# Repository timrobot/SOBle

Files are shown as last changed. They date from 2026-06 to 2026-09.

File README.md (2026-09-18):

# SOBle - SO101 Platform over BLE

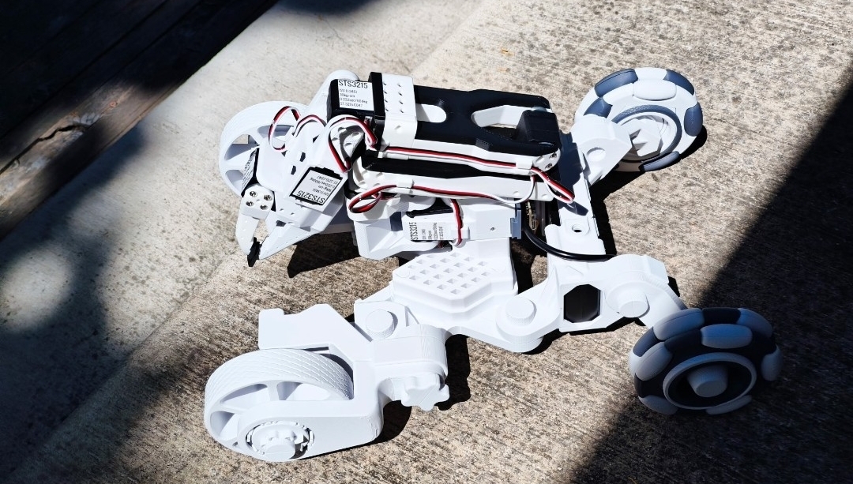
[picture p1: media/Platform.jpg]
SO101 Platform


*Image and Design attributed to @BIO-SS*

The SO101 Platform is a BLE-controlled four-wheeled differential drive with two powered wheels. It reports heading, pitch, roll, and wheel encoder positions. It is designed to work with the SO-101 robot arm, and supports an optional gripper-mounted camera for AprilTag detection or live video streaming over WiFi.

### Documentation 📖

For the full documention, check out the [wiki](https://github.com/timrobot/SOBle/wiki/Home) which contains both the [assembly guide](https://github.com/timrobot/SOBle/wiki/Assembly-Guide) and [tutorials](https://github.com/timrobot/SOBle/wiki/Home#Tutorials) for some classical algorithms involving Apriltags.

### Building the SO-101 Platform

You will need to first purchase the parts located in the [Sourcing Table](#sourcing-parts). Print out the parts in the [models folder](STL/), and then proceed to the [assembly guide](https://github.com/timrobot/SOBle/wiki/Assembly-Guide).

### Accessing the Viewer 📺

You can access the viewer [here](https://timrobot.github.io/SOBle). It allows you do to

 * ServoID flashing
 * Calibration file generation
 * Manual control over bluetooth
 * Sensor debugging

---

## Install

To control the robot over Python, you will need to install the SOBle package:

```bash
pip install "soble @ git+https://github.com/timrobot/SOBle.git@master"
```

---

## Quick usage

First, plug in the leader arm into your laptop. Make sure to record the port for your leader, as you will need it during connection.

```python
from soble import SO101Leader, SO101Platform

leader = SO101Leader("/dev/tty.usbmodem575E0032081")  # sub in the port of your leader here
leader.load_config("config.json")

platform = SO101Platform("Capybara")  # sub in the name of your robot/So101 Platform here

positions = leader.getMappedPositions()  # 6 ints, 0..4095
platform.setArmPositions(positions)
platform.drive(0, 0)

# if you have a raspi+camera attached, you can also detect apriltags
detections = platform.detectApriltags(estimate_tag_pose=True)
for tag_id, corners, R, t in detections:
    print(f"[{tag_id}]: {corners} {R} {t}")
```

---

## Sourcing parts

The following table lists the electronics you will need to purchase in addition to the prints you will need to make in [STL/](STL/), which will require 1-2 rolls of 1KG of PLA. Note that ideally you will need to solder at least a little, but solderless [hooked jumper wires](https://www.amazon.com/dp/B0BJ627S1X) are available for those who prefer not to.

| Part name | Qty | Unit Cost | Buy Link |
| --- | --- | --- | --- |
| Feetech STS3215 (1/345) | 2 | $12 | [Alibaba](https://www.alibaba.com/product-detail/Top-Seller-Low-Cost-Feetech-STS3215_1600999461525.html) |
| 7.4 V 2S LiPo battery (5200 mAh) | 1 | $36 | [Amazon](https://www.amazon.com/Zeee-Battery-5200mAh-Vehicles-Airplane/dp/B092CZGW2P) |
| Mini LiPo balance charger/discharger | 1 | $39 | [Amazon](https://www.amazon.com/B6-Battery-Charger-Discharger-Connectors/dp/B0F2H3XR6S) |
| Waveshare ESP32-S3-LCD-1.3 | 1 | $13 | [Waveshare](https://www.waveshare.com/esp32-s3-lcd-1.3.htm) (Standard version) |
| Barrel Connector (5.5x2.1) Male | 1 | $4 | [Amazon](https://www.amazon.com/Connector-Male-Female-Connectors-Security/dp/B0DVL9NDD1) |
| UBEC 5V 3A | 1 | $8 | [Amazon](https://www.amazon.com/jussming-Adjustable-UBEC-Regulator-Controllers/dp/B0GRGGM2T4) |
| USB-C female to 2-screw terminal | 1 | $8 | [Amazon](https://www.amazon.com/cablecc-Repair-Solderless-Connector-Terminal/dp/B0FY2HXYVF) |
| XT60 male to 2-screw terminal | 1 | $7 | [Amazon](https://www.amazon.com/YANBORONSN-Connectors-Terminal-Solderless-Aircraft/dp/B0FNJWYFT2) |
| Female to female jumper wires | 1 | $7 | [Amazon](https://www.amazon.com/EDGELEC-Breadboard-1pin-1pin-Connector-Multicolored/dp/B07GD312VG) |
| M2 x 6mm Socket Head Screws | 1 | $4 | [Amazon](https://www.amazon.com/Opfiue-100PCS-Socket-Screws-Stainless/dp/B0FVDZ7SZD) |
| USB-C to MicroUSB (2pcs) (optional) | 1 | $5 | [Amazon](https://www.amazon.com/JXMOX-Charger-Support-Compatible-Android/dp/B0D479B8DC) |
| Raspberry Pi Zero 2 W (optional) | 1 | $41 | [Amazon](https://www.amazon.com/CanaKit-Raspberry-Zero-Basic-Official/dp/B0CT1Y3CQJ) |
| Arducam Pi Camera Module 3 (IMX708, autofocus) (optional) | 1 | $34 | [Amazon](https://www.amazon.com/Arducam-Raspberry-Camera-Autofocus-15-22pin/dp/B0C9PYCV9S) |

Required electronics cost **$150**, primarily due to the battery and charger. Optional electronics add an additional **$80** (USB cable, Pi Zero 2 W, camera), for a grand total of **$230** plus filament.

The **SO101 follower arm** (Feetech servos and its own controller) is not included in the table above and must be purchased separately.

If you still need arm servos, order the two drive **STS3215** units from the table at the same time as the arm servos to save on shipping.

---

## Examples

A [3D viewer](https://github.com/timrobot/SOBle/releases) is available out of the box to control the robot with a leader arm. It also supports servo ID flashing, calibration, sensor displays, and 3D AprilTag detections—and uses the soble API directly, with no hidden functions. The code examples below demonstrate a few things you can do with the API.

| Script | Description |
| --- | --- |
| [`examples/lead-follow.py`](examples/lead-follow.py) | Send mapped leader positions → follower |
| [`examples/soble-app.py`](examples/soble-app.py) | Drive using WASD, mapped leader → follower, visualize tags on screen. *Raspi+Camera required.* |

---

## Code reference — Class `SO101Leader`

```python
from soble import SO101Leader

leader = SO101Leader("/dev/tty.usbmodem575E0032081") # Mac
leader = SO101Leader("/dev/ttyACM0") # Linux
leader = SO101Leader("COM3") # Windows
leader.load_config("config.json")  # or pass config= in the constructor

```

| Method | Returns | Notes |
| --- | --- | --- |
| `CalibrationConfig.from_path(path)` | `CalibrationConfig` | Load calibration from JSON (see [`examples/config.json`](examples/config.json)). |
| `CalibrationConfig.limits_arrays()` | `tuple[np.ndarray, np.ndarray]` | Leader and follower limit arrays, each shape **(6, 2)** with `[min, max]` per joint. |
| `SO101Leader(port, *, config=None, baud=1000000)` | — | **`port` required**. Serial starts on init. Pass `config` or call `load_config()` for mapping. |
| `load_config(config)` | `None` | Set leader/follower limit mapping from a `CalibrationConfig` or JSON path. |
| `config` (property) | `CalibrationConfig \| None` | Active calibration, if loaded. |
| `getArmPositions()` | `list[int]` | **6** leader joint raws **0 … 4095**, or **`[]`** if not ready. |
| `getMappedPositions()` | `list[int]` | **6** follower-mapped raws **0 … 4095**, or leader raws **1:1** if no config; **`[]`** if not ready. |
| `setArmPositions(joints)` | `None` | Engage leader torque, or pass **`[]`** to release (backdrivable; default). |

`load_config` accepts a `CalibrationConfig` instance or a path to the standard SO101 JSON file. See [`examples/config.json`](examples/config.json) and `CalibrationConfig` in `soble.calibration_config`.

## Code reference — Class `SO101Platform`

```python
from soble import SO101Platform

platform = SO101Platform("Capybara") # or whatever the name appears on the LCD

```

| Method | Returns | Notes |
| --- | --- | --- |
| `SO101Platform(device_name: str, *, reconnect_delay_s=0.25, log_state=True, autostart=True)` | — | With `autostart=True` (default), starts BLE on init; pass `autostart=False` to connect later via `start()`. |
| `start()` | `None` | *Optional.* Restart communication after `stop()`. |
| `stop()` | `None` | Stop communication; clear tag state. |
| `running` (property) | `bool` | `True` if alive, else `False` |
| `last_notify_age_s()` | `float` or `None` | Seconds since a data packet has arrived. |

### Core Commands

| Method | Returns | Notes |
| --- | --- | --- |
| `drive(left, right, left2=0, right2=0)` | — | Each **−125 … 125** (clamped). Optional `left2`/`right2` for the second wheel pair. |
| `wheelEncoders()` | `tuple[int, int, int, int]` | `(left, right, left2, right2)`, each **0 … 4095** (four 12-bit values packed in **6** bytes). |
| `setArmPositions(joints)` | — | **6** values, each **0 … 4095** (12-bit). Order **J1 … J6**. Pass **`[]`** to disengage arm. |
| `getArmPositions()` | `list[int]` | **6** raw encoder values **J1 … J6** from follower arm; **`[]`** if no state yet. |
| `setLegPositions(joints)` | — | **8** values, each **0 … 4095** (12-bit). Order **J11 … J18**. Pass **`[]`** to disengage legs. |
| `getLegPositions()` | `list[int]` | **8** raw encoder values **J11 … J18**; **`[]`** if no state yet. |
| `imuRotation()` | `tuple[float, float, float]` | IMU roll, pitch, heading in **degrees**. |
| `imuQuaternion()` | `tuple[float, float, float, float]` | IMU unit quaternion **(w, x, y, z)**. |

### Camera / AprilTag Commands

| Method | Returns | Notes |
| --- | --- | --- |
| `raspiAlive()` | `bool` | Pi serial seen recently. |
| `detectApriltags(estimate_tag_pose=False, camera_params=..., tag_size=3)` | `list` | Tag id plus four corner `(x, y)` pairs (**lb, rb, rt, lt**). Returns **`[]`** if no state yet or no tags in view. Pass `estimate_tag_pose=True` for `(tag_id, corners, R, tvec)` per tag. `tag_size` is the physical outer edge length in your chosen unit (e.g. inches); `tvec` uses the same unit. |
| `setTagFamily(family)` | — | `'tag16h5'`, `'tag25h9'`, or `'tag36h11'`. |

#### AprilTags — corners and image

*Specifications:*

| Item | Value |
| --- | --- |
| Image size | **1280 × 720** pixels |
| Tag family | **tag16h5** by default; use `setTagFamily()` for **tag25h9** or **tag36h11** |
| Corner order | **lb, rb, rt, lt** — each corner `(x, y)` float pixels |
| `x` range | **0 … 1280** |
| `y` range | **0 … 720** |
| Max tags | **10** |
| `R` | **3 × 3** rotation matrix (`np.ndarray`, `float64`) |
| `t` | **3 × 1** translation vector (`np.ndarray`, `float64`); same unit as `tag_size` when pose is estimated |

**Example** — two tag16h5 tags in view:

```python
>>> platform.detectApriltags()
[
    (0, [
        (612.4, 388.2),   # lb
        (667.8, 388.2),   # rb
        (667.8, 331.6),   # rt
        (612.4, 331.6),   # lt
    ]),
    (3, [
        (118.4, 142.3),
        (182.0, 140.0),
        (180.2, 198.1),
        (120.0, 200.5),
    ]),
]
```

Each list entry is `(tag_id, corners_px)` with **four** `(x, y)` pixel pairs in **lb → rb → rt → lt** order.

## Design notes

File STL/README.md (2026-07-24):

## Required STL Print List (VEX front wheel)

> Note: This list assumes that you are using the VEX 4" Traction wheel for the front wheel. If you aren't please refer to the list at the bottom of the page. You will be required to print the wheel in TPU for the wheel to have proper grip.

| STL part | Qty | Repo link |
| ---- | --- | ---- |
| Supported Ball Bearing | 24 | [Supported Ball Bearing.stl](KiloChassis/Bearing/Supported%20Ball%20Bearing.stl) |
| Omni Wheel Core | 2 | [Omni Wheel Core.stl](KiloChassis/Rear%20Deadwheel/Omni%20Wheel/Omni%20Wheel%20Core.stl) |
| Bearing Inner Ring | 4 | [Bearing Inner Ring.stl](KiloChassis/Bearing/Bearing%20Inner%20Ring.stl) |
| Ball Retainer | 4 | [Ball Retainer.stl](KiloChassis/Bearing/Ball%20Retainer.stl) |
| Roller | 20 | [Roller.stl](KiloChassis/Rear%20Deadwheel/Omni%20Wheel/Roller.stl) |
| Omni Wheel Frame | 8 | [Omni Wheel Frame.stl](KiloChassis/Rear%20Deadwheel/Omni%20Wheel/Omni%20Wheel%20Frame.stl) |
| Hub Retaining Ring | 4 | [Hub Retaining Ring.stl](KiloChassis/Rear%20Deadwheel/Omni%20Wheel/Hub%20Retaining%20Ring.stl) |
| Rear Base | 1 | [Rear Base.stl](KiloChassis/Base%20Components/Rear%20Base.stl) |
| Main Base Bolt | 4 | [Main Base Bolt v2.stl](KiloChassis/Bolts/Main%20Base%20Bolt%20v2.stl) |
| Rear Drive Bolt | 2 | [Rear Drive Bolt.stl](KiloChassis/Bolts/Rear%20Drive%20Bolt.stl) |
| Rear Deadwheel Bracket | 2 | [Rear Deadwheel Bracket.stl](KiloChassis/Rear%20Deadwheel/Rear%20Deadwheel%20Bracket.stl) |
| Rear Wheel Nut | 2 | [Rear Wheel Nut.stl](KiloChassis/Rear%20Deadwheel/Rear%20Wheel%20Nut.stl) |
| Servo Coupler | 2 | [Servo Coupler.stl](KiloChassis/Front%20Drive/VEX%20Front%20Axle/Servo%20Coupler.stl) |
| Servo Clamp | 2 | [Servo Clamp.stl](KiloChassis/Front%20Drive/Servo%20Clamp.stl) |
| Servo Bracket Left | 1 | [Servo Bracket Left.stl](KiloChassis/Front%20Drive/Servo%20Bracket%20Left.stl) |
| Servo Bracket Right | 1 | [Servo Bracket Right.stl](KiloChassis/Front%20Drive/Servo%20Bracket%20Right.stl) |
| Arm Base | 1 | [Arm Base.stl](KiloChassis/Base%20Components/Arm%20Base.stl) |
| Wheel Bearing Bracket Left | 1 | [Wheel Bearing Bracket Left.stl](KiloChassis/Front%20Drive/Wheel%20Bearing%20Bracket%20Left.stl) |
| Wheel Bearing Bracket Right | 1 | [Wheel Bearing Bracket Right.stl](KiloChassis/Front%20Drive/Wheel%20Bearing%20Bracket%20Right.stl) |
| Front Axle Halve | 4 | [Front Axle Halve.stl](KiloChassis/Front%20Drive/VEX%20Front%20Axle/Front%20Axle%20Halve.stl) |
| Front Drive Bolt | 2 | [Front Drive Bolt v2.stl](KiloChassis/Bolts/Front%20Drive%20Bolt%20v2.stl) |
| Arm Retainer Pin Halve | 8 | [Arm Retainer Pin Halve.stl](KiloChassis/Base%20Components/Arm%20Retainer/Arm%20Retainer%20Pin%20Halve.stl) |
| Arm Pin Half Bracket | 4 | [Arm Pin Half Bracket.stl](KiloChassis/Base%20Components/Arm%20Retainer/Arm%20Pin%20Half%20Bracket.stl) |
| Arm Pin Mini Bracket | 4 | [Arm Pin Mini Bracket.stl](KiloChassis/Base%20Components/Arm%20Retainer/Arm%20Pin%20Mini%20Bracket.stl) |
| Arm Pin Bolt | 4 | [Arm Pin Bolt.stl](KiloChassis/Bolts/Arm%20Pin%20Bolt.stl) |
| ESP32 Mount | 1 | [ESP32 Mount.stl](KiloChassis/Base%20Components/ESP32%20Mount.stl) |
| ESP32 Bolt | 1 | [ESP32 Bolt.stl](KiloChassis/Bolts/ESP32%20Bolt.stl) |
| Bus Adapter Bracket | 1 | [Bus Adapter Bracket.stl](KiloChassis/Bus%20Adapter/Bus%20Adapter%20Bracket.stl) |
| Bus Adapter Clamping Foot | 2 | [Bus Adapter Clamping Foot.stl](KiloChassis/Bus%20Adapter/Bus%20Adapter%20Clamping%20Foot.stl) |
| Bus Adapter Clamp Bolt | 2 | [Bus Adapter Clamp Bolt.stl](KiloChassis/Bolts/Bus%20Adapter%20Clamp%20Bolt.stl) |
| Bus Adapter Bracket Top | 1 | [Bus Adapter Bracket Top.stl](KiloChassis/Bus%20Adapter/Bus%20Adapter%20Bracket%20Top.stl) |
| Bus Adapter Bracket Bottom | 1 | [Bus Adapter Bracket Bottom.stl](KiloChassis/Bus%20Adapter/Bus%20Adapter%20Bracket%20Bottom.stl) |
| Bus Adapter Bracket Retainer | 1 | [Bus Adapter Bracket Retainer.stl](KiloChassis/Bus%20Adapter/Bus%20Adapter%20Bracket%20Retainer.stl) |
| Bus Adapter Retainer Bolt | 1 | [Bus Adapter Retainer Bolt.stl](KiloChassis/Bolts/Bus%20Adapter%20Retainer%20Bolt.stl) |
| Battery Lock | 1 | [Battery Lock.stl](KiloChassis/Base%20Components/Battery%20Lock.stl) |

## Required STL Print List (TPU front wheel)

| STL part | Qty | Repo link |
| ---- | --- | ---- |
| Supported Ball Bearing | 24 | [Supported Ball Bearing.stl](KiloChassis/Bearing/Supported%20Ball%20Bearing.stl) |
| Omni Wheel Core | 2 | [Omni Wheel Core.stl](KiloChassis/Rear%20Deadwheel/Omni%20Wheel/Omni%20Wheel%20Core.stl) |
| Bearing Inner Ring | 4 | [Bearing Inner Ring.stl](KiloChassis/Bearing/Bearing%20Inner%20Ring.stl) |
| Ball Retainer | 4 | [Ball Retainer.stl](KiloChassis/Bearing/Ball%20Retainer.stl) |
| Roller | 20 | [Roller.stl](KiloChassis/Rear%20Deadwheel/Omni%20Wheel/Roller.stl) |
| Omni Wheel Frame | 8 | [Omni Wheel Frame.stl](KiloChassis/Rear%20Deadwheel/Omni%20Wheel/Omni%20Wheel%20Frame.stl) |
| Hub Retaining Ring | 4 | [Hub Retaining Ring.stl](KiloChassis/Rear%20Deadwheel/Omni%20Wheel/Hub%20Retaining%20Ring.stl) |
| Rear Base | 1 | [Rear Base.stl](KiloChassis/Base%20Components/Rear%20Base.stl) |
| Main Base Bolt | 4 | [Main Base Bolt v2.stl](KiloChassis/Bolts/Main%20Base%20Bolt%20v2.stl) |
| Rear Drive Bolt | 2 | [Rear Drive Bolt.stl](KiloChassis/Bolts/Rear%20Drive%20Bolt.stl) |
| Rear Deadwheel Bracket | 2 | [Rear Deadwheel Bracket.stl](KiloChassis/Rear%20Deadwheel/Rear%20Deadwheel%20Bracket.stl) |
| Rear Wheel Nut | 2 | [Rear Wheel Nut.stl](KiloChassis/Rear%20Deadwheel/Rear%20Wheel%20Nut.stl) |
| Servo Coupler | 2 | [Servo Coupler.stl](KiloChassis/Front%20Drive/Front%20Axle/Servo%20Coupler.stl) |
| Servo Clamp | 2 | [Servo Clamp.stl](KiloChassis/Front%20Drive/Servo%20Clamp.stl) |
| Servo Bracket Left | 1 | [Servo Bracket Left.stl](KiloChassis/Front%20Drive/Servo%20Bracket%20Left.stl) |
| Servo Bracket Right | 1 | [Servo Bracket Right.stl](KiloChassis/Front%20Drive/Servo%20Bracket%20Right.stl) |
| Arm Base | 1 | [Arm Base.stl](KiloChassis/Base%20Components/Arm%20Base.stl) |
| Wheel Bearing Bracket Left | 1 | [Wheel Bearing Bracket Left.stl](KiloChassis/Front%20Drive/Wheel%20Bearing%20Bracket%20Left.stl) |
| Wheel Bearing Bracket Right | 1 | [Wheel Bearing Bracket Right.stl](KiloChassis/Front%20Drive/Wheel%20Bearing%20Bracket%20Right.stl) |
| Front Axle Halve | 4 | [Front Axle Halve.stl](KiloChassis/Front%20Drive/Front%20Axle/Front%20Axle%20Halve.stl) |
| Front Axle Halve | 4 | [Front Axle Halve.stl](KiloChassis/Front%20Drive/Front%20Axle/Front%20Axle%20Halve.stl) |
| Front Axle Clip | 2 | [Front Axle Clip.stl](KiloChassis/Front%20Drive/Front%20Axle/Front%20Axle%20Clip.stl) |
| Front Wheels Grippy v2 | 2 | [Front Wheels Grippy v2.stl](KiloChassis/Front%20Drive/Front%20Wheels%20Grippy%20v2.stl) |
| Front Drive Bolt | 2 | [Front Drive Bolt v2.stl](KiloChassis/Bolts/Front%20Drive%20Bolt%20v2.stl) |
| Arm Retainer Pin Halve | 8 | [Arm Retainer Pin Halve.stl](KiloChassis/Base%20Components/Arm%20Retainer/Arm%20Retainer%20Pin%20Halve.stl) |
| Arm Pin Half Bracket | 4 | [Arm Pin Half Bracket.stl](KiloChassis/Base%20Components/Arm%20Retainer/Arm%20Pin%20Half%20Bracket.stl) |
| Arm Pin Mini Bracket | 4 | [Arm Pin Mini Bracket.stl](KiloChassis/Base%20Components/Arm%20Retainer/Arm%20Pin%20Mini%20Bracket.stl) |
| Arm Pin Bolt | 4 | [Arm Pin Bolt.stl](KiloChassis/Bolts/Arm%20Pin%20Bolt.stl) |
| ESP32 Mount | 1 | [ESP32 Mount.stl](KiloChassis/Base%20Components/ESP32%20Mount.stl) |
| ESP32 Bolt | 1 | [ESP32 Bolt.stl](KiloChassis/Bolts/ESP32%20Bolt.stl) |
| Bus Adapter Bracket | 1 | [Bus Adapter Bracket.stl](KiloChassis/Bus%20Adapter/Bus%20Adapter%20Bracket.stl) |
| Bus Adapter Clamping Foot | 2 | [Bus Adapter Clamping Foot.stl](KiloChassis/Bus%20Adapter/Bus%20Adapter%20Clamping%20Foot.stl) |
| Bus Adapter Clamp Bolt | 2 | [Bus Adapter Clamp Bolt.stl](KiloChassis/Bolts/Bus%20Adapter%20Clamp%20Bolt.stl) |
| Bus Adapter Bracket Top | 1 | [Bus Adapter Bracket Top.stl](KiloChassis/Bus%20Adapter/Bus%20Adapter%20Bracket%20Top.stl) |
| Bus Adapter Bracket Bottom | 1 | [Bus Adapter Bracket Bottom.stl](KiloChassis/Bus%20Adapter/Bus%20Adapter%20Bracket%20Bottom.stl) |
| Bus Adapter Bracket Retainer | 1 | [Bus Adapter Bracket Retainer.stl](KiloChassis/Bus%20Adapter/Bus%20Adapter%20Bracket%20Retainer.stl) |
| Bus Adapter Retainer Bolt | 1 | [Bus Adapter Retainer Bolt.stl](KiloChassis/Bolts/Bus%20Adapter%20Retainer%20Bolt.stl) |
| Battery Lock | 1 | [Battery Lock.stl](KiloChassis/Base%20Components/Battery%20Lock.stl) |

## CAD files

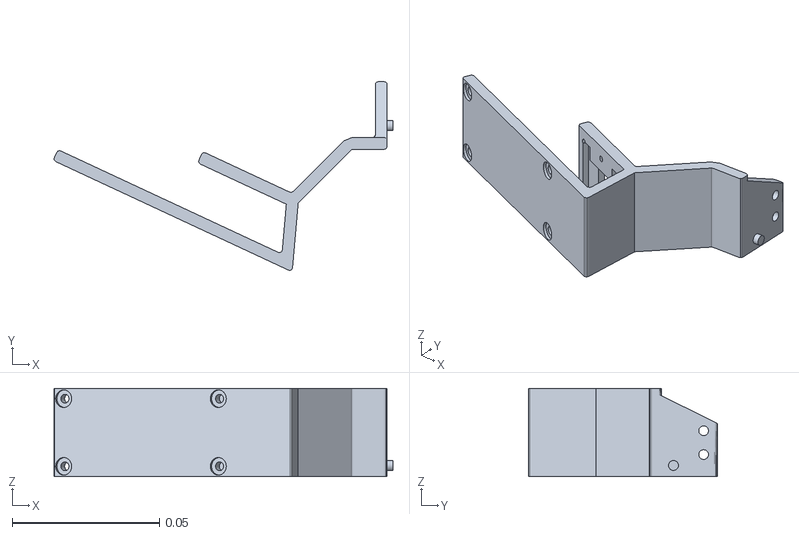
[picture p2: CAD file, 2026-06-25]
Simulation/SO101/assets/SO-ARM101_IMX708_wrist_mount.stl
0.115 x 0.0641 x 0.03

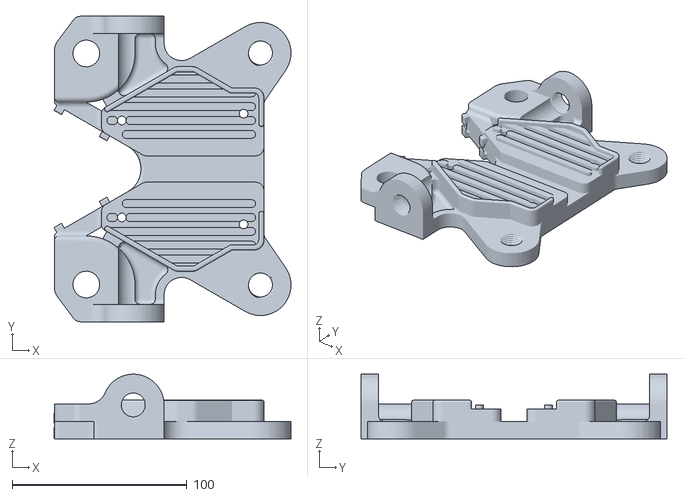
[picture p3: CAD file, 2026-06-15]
STL/KiloChassis/Base Components/Arm Base.stl
135.8 x 175.1 x 37.0

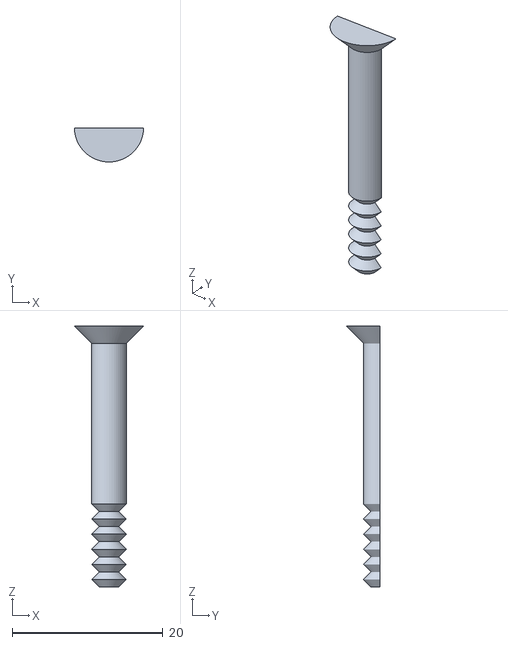
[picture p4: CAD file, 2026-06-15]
STL/KiloChassis/Base Components/Arm Retainer/Arm Retainer Pin Halve.stl
9.20 x 4.50 x 34.6

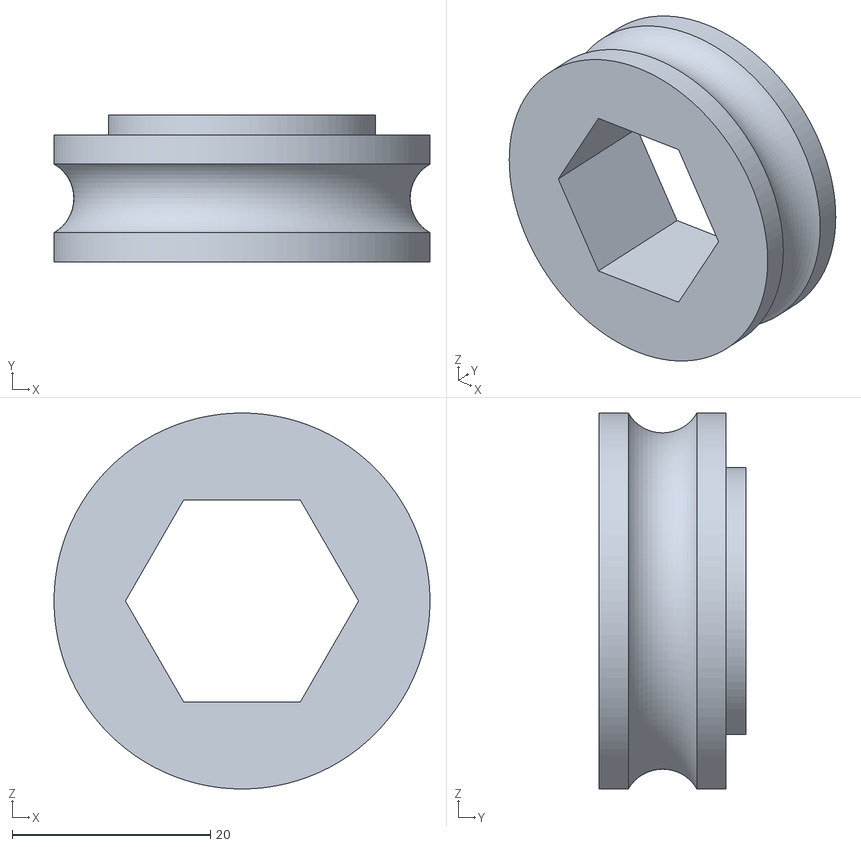
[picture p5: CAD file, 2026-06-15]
STL/KiloChassis/Bearing/Bearing Inner Ring.stl
38.0 x 14.8 x 38.0

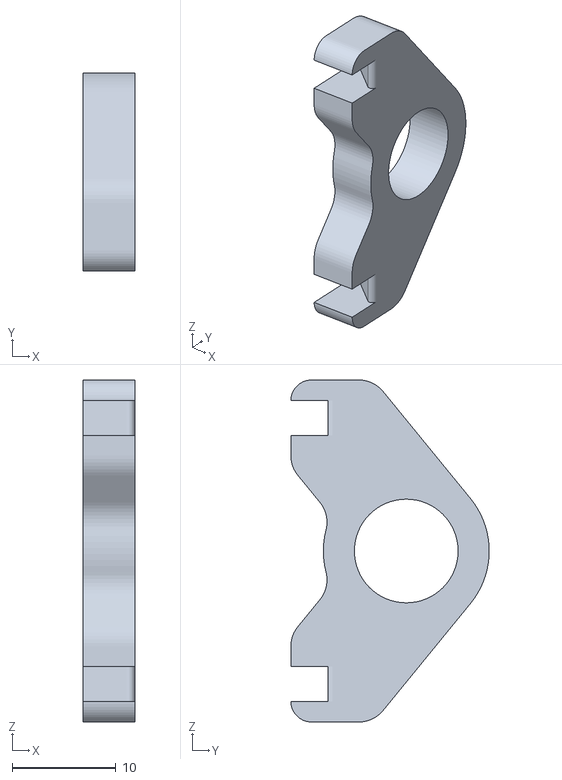
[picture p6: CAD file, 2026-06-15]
STL/KiloChassis/Bus Adapter/Bus Adapter Bracket Retainer.stl
5.00 x 19.1 x 33.0

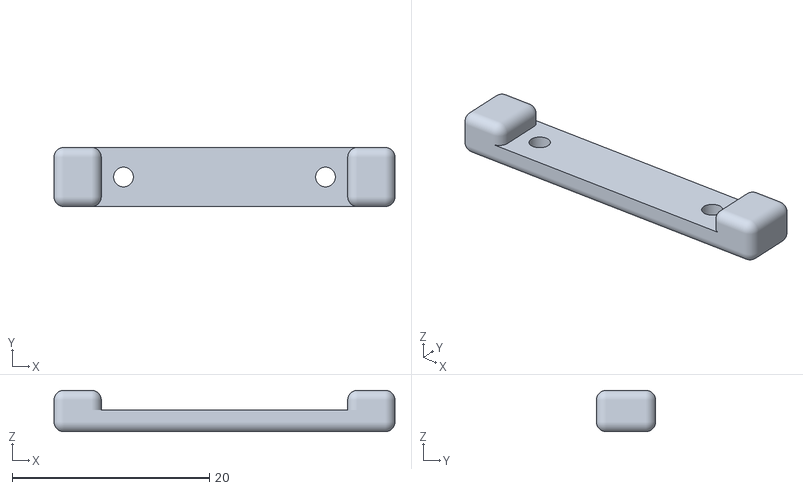
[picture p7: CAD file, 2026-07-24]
STL/KiloChassis/Front Drive/Servo Clamp.stl
34.6 x 6.00 x 4.20

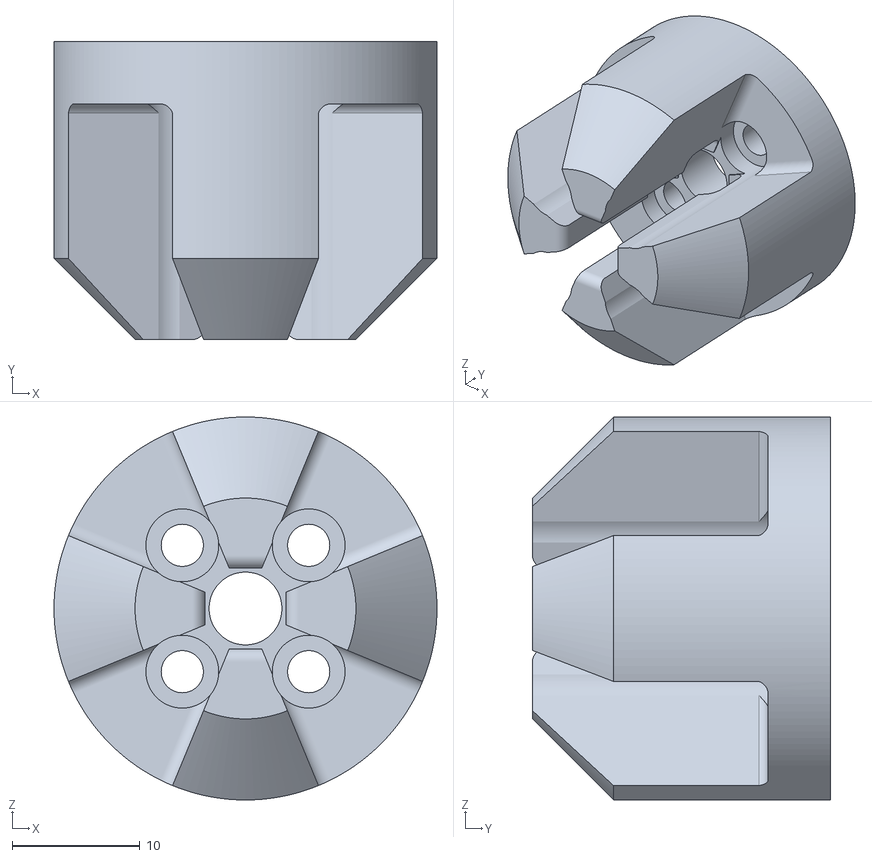
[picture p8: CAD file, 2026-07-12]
STL/KiloChassis/Front Drive/VEX Front Axle/Servo Coupler.stl
30.0 x 23.3 x 30.0

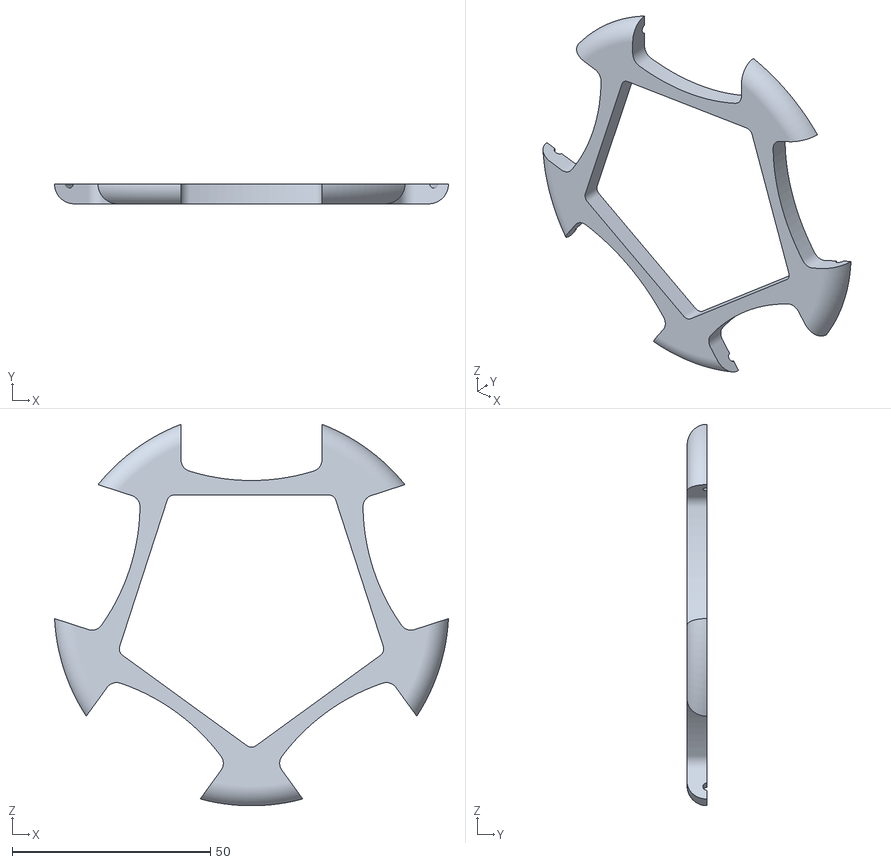
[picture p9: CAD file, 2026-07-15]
STL/KiloChassis/Rear Deadwheel/Omni Wheel/Omni Wheel Frame.stl
99.5 x 5.00 x 96.3

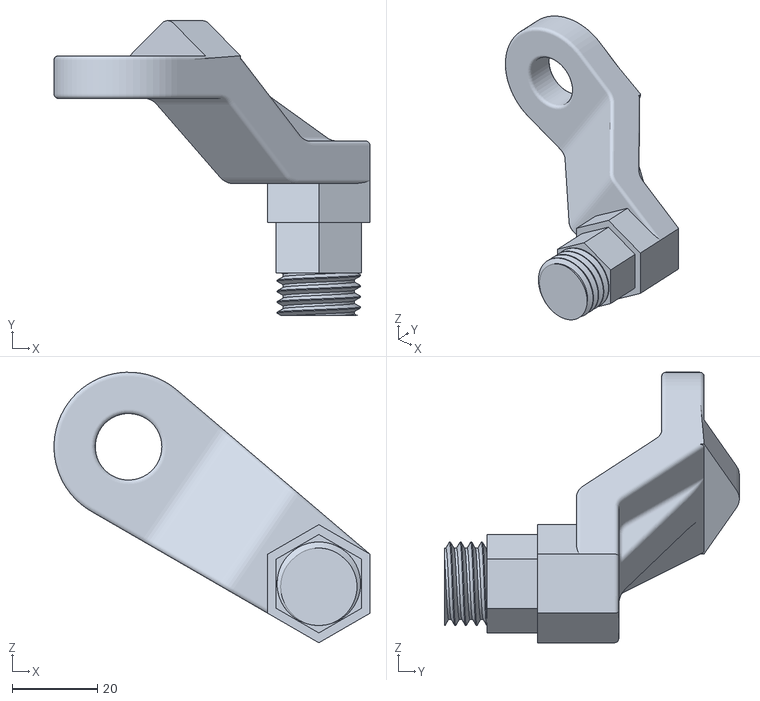
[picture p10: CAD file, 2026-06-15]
STL/KiloChassis/Rear Deadwheel/Rear Deadwheel Bracket.stl
74.1 x 69.2 x 63.5

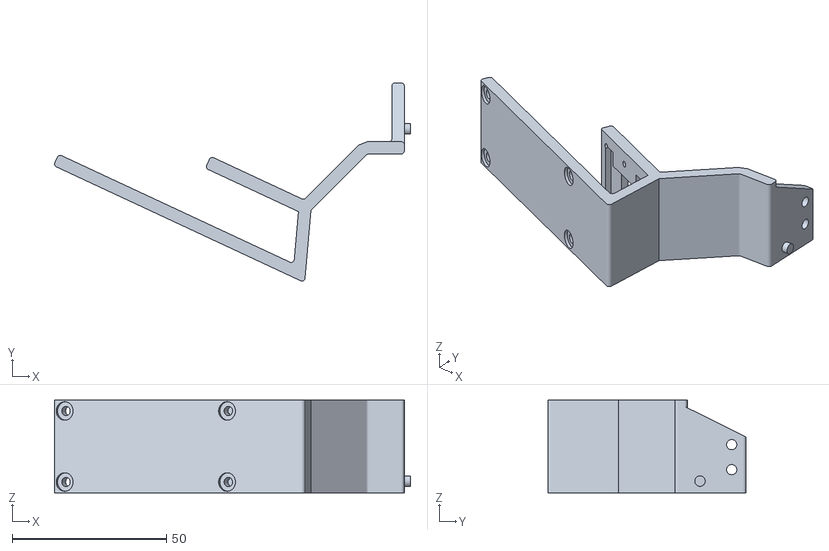
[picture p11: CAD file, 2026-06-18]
STL/Optional/SO-ARM101_IMX708_wrist_mount.stl
115.2 x 64.1 x 30.0

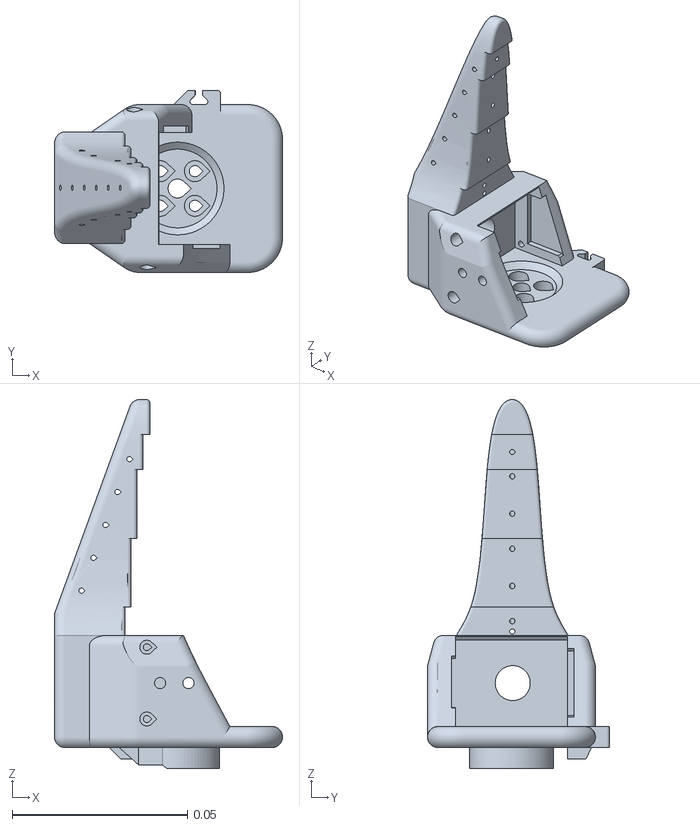
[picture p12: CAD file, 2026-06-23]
Simulation/SO101/assets/wrist_roll_follower_so101_v1.stl
0.0652 x 0.052 x 0.105

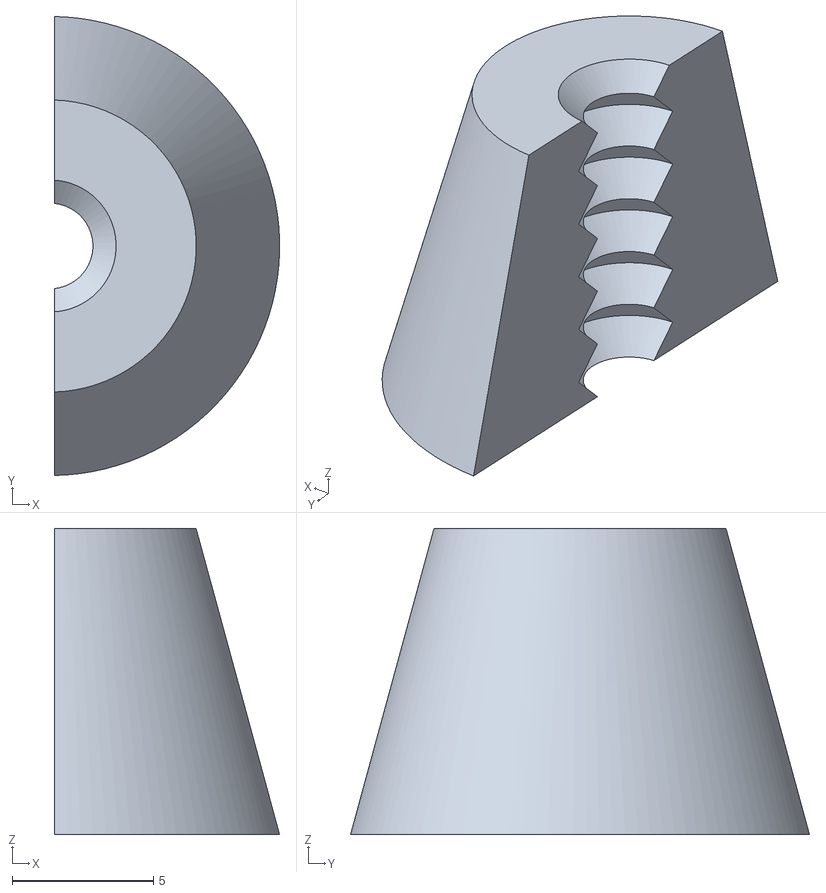
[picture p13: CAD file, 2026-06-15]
STL/KiloChassis/Base Components/Arm Retainer/Arm Pin Half Bracket.stl
7.96 x 16.2 x 10.8

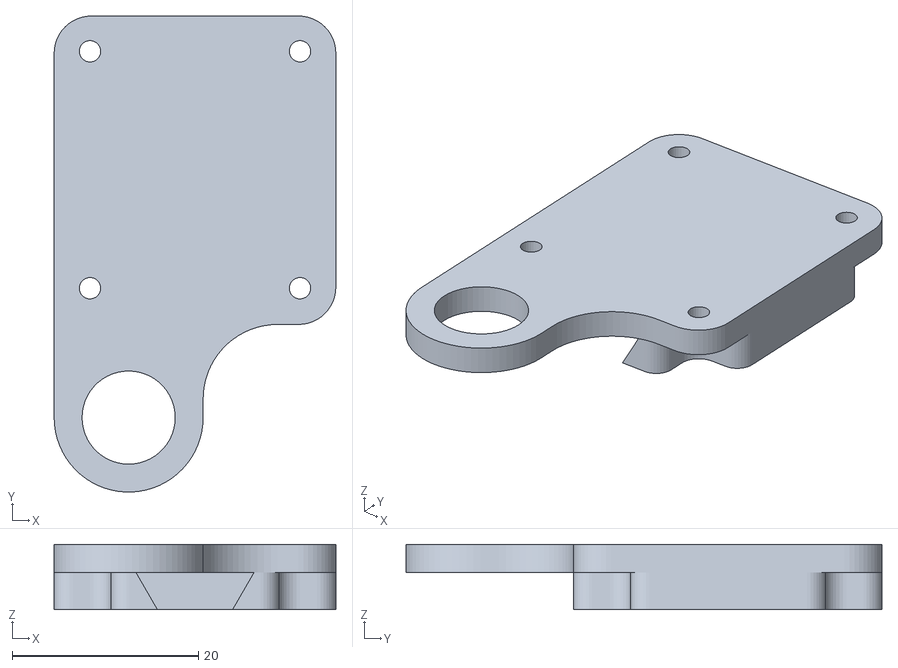
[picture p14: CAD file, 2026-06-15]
STL/KiloChassis/Base Components/ESP32 Mount.stl
30.2 x 51.1 x 7.00

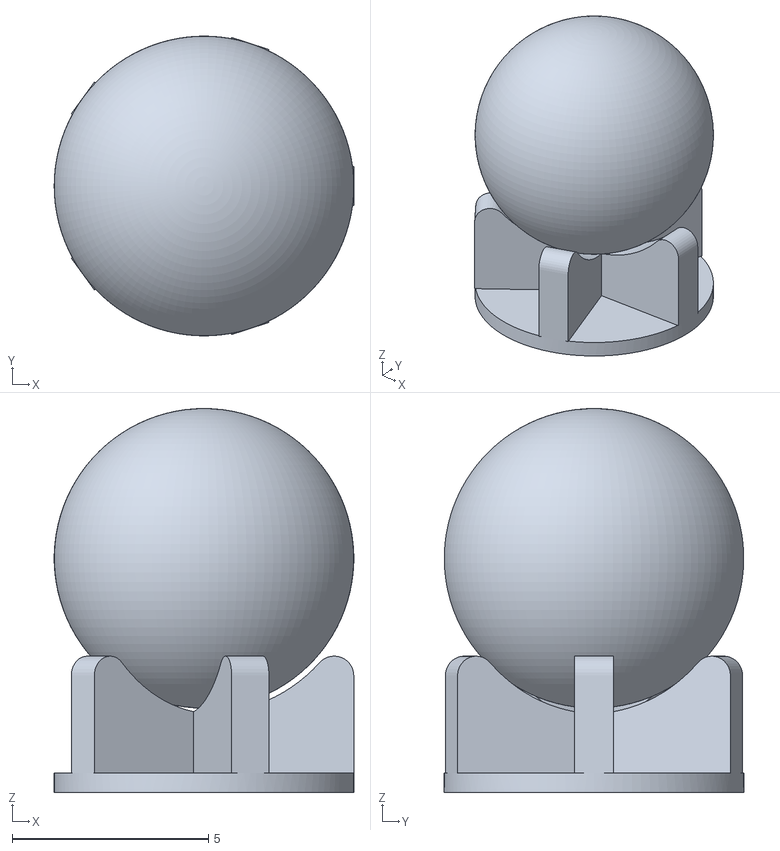
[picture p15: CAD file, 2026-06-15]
STL/KiloChassis/Bearing/Supported Ball Bearing.stl
7.64 x 7.64 x 9.79

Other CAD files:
STL/KiloChassis/Bus Adapter/Bus Adapter Bracket.stl
STL/KiloChassis/Front Drive/Front Wheels Grippy v2.stl
STL/KiloChassis/Front Drive/VEX Front Axle/Front Axle Halve.stl
STL/KiloChassis/Rear Deadwheel/Omni Wheel/Roller.stl
STL/KiloChassis/Base Components/Arm Retainer/Arm Pin Mini Bracket.stl
STL/KiloChassis/Base Components/Battery Lock.stl
STL/KiloChassis/Base Components/Rear Base.stl
STL/KiloChassis/Bearing/Ball Retainer.stl
STL/KiloChassis/Bolts/Arm Pin Bolt.stl
STL/KiloChassis/Bolts/Bus Adapter Clamp Bolt.stl
STL/KiloChassis/Bolts/Bus Adapter Retainer Bolt.stl
STL/KiloChassis/Bolts/ESP32 Bolt.stl
STL/KiloChassis/Bolts/Front Drive Bolt v2.stl
STL/KiloChassis/Bolts/Front Drive Bolt.stl
STL/KiloChassis/Bolts/Main Base Bolt v2.stl
STL/KiloChassis/Bolts/Main Base Bolt.stl
STL/KiloChassis/Bolts/Rear Drive Bolt.stl
STL/KiloChassis/Bus Adapter/Bus Adapter Bracket Bottom.stl
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

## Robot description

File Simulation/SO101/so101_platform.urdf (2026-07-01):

<?xml version="1.0"?>
<!-- SO-101 differential-drive mobile base (STS3215 1/345 front wheels).
     Converted from so101_platform.xml (MuJoCo).
     Axes: +X forward, +Y left, +Z up (matches so101_new_calib / Panda sim).
     Wheel layout:
      distance from center to front wheels (+X): 5.75 in
      distance from wheel to wheel: 9.5 in
      distance from center to back wheels (-X): 5.75 in
      wheel diameter: 4 in
      wheel width: 1 in
     Front left/right wheels: continuous joints (encoder angle maps to 12-bit raw).
     Rear wheels: passive omni casters (MuJoCo ball joints; URDF uses continuous spin). -->
<robot name="so101_platform">

  <!-- Ground / odometry frame. Platform body origin sits at wheel-axle height. -->
  <link name="base_footprint"/>

  <link name="platform">
    <inertial>
      <origin xyz="0 0 0" rpy="0 0 0"/>
      <mass value="2.5"/>
      <inertia ixx="0.02" iyy="0.03" izz="0.04" ixy="0" ixz="0" iyz="0"/>
    </inertial>
    <visual name="chassis_visual">
      <origin xyz="0 0 0" rpy="0 0 3.141592653589793"/>
      <geometry>
        <mesh filename="assets/ChassisV2.stl"/>
      </geometry>
      <material name="chassis_gray">
        <color rgba="0.15 0.15 0.15 1"/>
      </material>
    </visual>
    <collision name="chassis_collision">
      <origin xyz="0 0 0" rpy="0 0 0"/>
      <geometry>
        <box size="0.3048 0.254 0.0508"/>
      </geometry>
    </collision>
  </link>

  <!-- MuJoCo freejoint → URDF floating base (6-DOF). -->
  <joint name="platform_free" type="floating">
    <parent link="base_footprint"/>
    <child link="platform"/>
    <origin xyz="0 0 0.0508" rpy="0 0 0"/>
  </joint>

  <!-- Mount frame for SO101 arm (matches arm_mount site in MJCF). -->
  <link name="arm_mount"/>

  <joint name="arm_mount_joint" type="fixed">
    <parent link="platform"/>
    <child link="arm_mount"/>
    <origin xyz="0 0 0" rpy="0 0 0"/>
  </joint>

  <link name="wheel_fl">
    <inertial>
      <origin xyz="0 0 0" rpy="0 0 0"/>
      <mass value="0.15"/>
      <inertia ixx="0.0002" iyy="0.0003" izz="0.0002" ixy="0" ixz="0" iyz="0"/>
    </inertial>
    <visual name="wheel_fl_visual">
      <origin xyz="0 0 0" rpy="0 0 0"/>
      <geometry>
        <mesh filename="assets/FrontWheel.stl"/>
      </geometry>
      <material name="wheel_dark">
        <color rgba="0.1 0.1 0.1 1"/>
      </material>
    </visual>
    <collision name="wheel_fl_collision">
      <origin xyz="0 0 0" rpy="1.5707963267948966 0 0"/>
      <geometry>
        <cylinder radius="0.0508" length="0.0254"/>
      </geometry>
    </collision>
  </link>

  <!-- STS servo ID 7 on hardware. -->
  <joint name="wheel_left" type="continuous">
    <parent link="platform"/>
    <child link="wheel_fl"/>
    <origin xyz="0.14605 0.12065 0" rpy="0 0 0"/>
    <axis xyz="0 1 0"/>
    <dynamics damping="0.60" friction="0.052"/>
  </joint>

  <link name="wheel_fr">
    <inertial>
      <origin xyz="0 0 0" rpy="0 0 0"/>
      <mass value="0.15"/>
      <inertia ixx="0.0002" iyy="0.0003" izz="0.0002" ixy="0" ixz="0" iyz="0"/>
    </inertial>
    <visual name="wheel_fr_visual">
      <origin xyz="0 0 0" rpy="0 0 0"/>
      <geometry>
        <mesh filename="assets/FrontWheel.stl"/>
      </geometry>
      <material name="wheel_dark"/>
    </visual>
    <collision name="wheel_fr_collision">
      <origin xyz="0 0 0" rpy="1.5707963267948966 0 0"/>
      <geometry>
        <cylinder radius="0.0508" length="0.0254"/>
      </geometry>
    </collision>
  </link>

  <!-- STS servo ID 8 on hardware. -->
  <joint name="wheel_right" type="continuous">
    <parent link="platform"/>
    <child link="wheel_fr"/>
    <origin xyz="0.14605 -0.12065 0" rpy="0 0 0"/>
    <axis xyz="0 1 0"/>
    <dynamics damping="0.60" friction="0.052"/>
  </joint>

  <link name="wheel_rl">
    <inertial>
      <origin xyz="0 0 0" rpy="0 0 0"/>
      <mass value="0.10"/>
      <inertia ixx="0.00015" iyy="0.0002" izz="0.00015" ixy="0" ixz="0" iyz="0"/>
    </inertial>
    <visual name="wheel_rl_visual">
      <origin xyz="0 0 0" rpy="0 0 0"/>
      <geometry>
        <mesh filename="assets/Omniwheel.stl"/>
      </geometry>
      <material name="omni_gray">
        <color rgba="0.35 0.35 0.35 1"/>
      </material>
    </visual>
    <collision name="wheel_rl_collision">
      <origin xyz="0 0 0" rpy="1.5707963267948966 0 0"/>
      <geometry>
        <cylinder radius="0.0508" length="0.0254"/>
      </geometry>
    </collision>
  </link>

  <!-- Passive omni caster (MJCF ball joint; URDF models wheel spin only). -->
  <joint name="omni_left" type="continuous">
    <parent link="platform"/>
    <child link="wheel_rl"/>
    <origin xyz="-0.14605 0.12065 0" rpy="0 0 0"/>
    <axis xyz="0 1 0"/>
    <dynamics damping="0.01" friction="0.001"/>
  </joint>

  <link name="wheel_rr">
    <inertial>
      <origin xyz="0 0 0" rpy="0 0 0"/>
      <mass value="0.10"/>
      <inertia ixx="0.00015" iyy="0.0002" izz="0.00015" ixy="0" ixz="0" iyz="0"/>
    </inertial>
    <visual name="wheel_rr_visual">
      <origin xyz="0 0 0" rpy="0 0 0"/>
      <geometry>
        <mesh filename="assets/Omniwheel.stl"/>
      </geometry>
      <material name="omni_gray"/>
    </visual>
    <collision name="wheel_rr_collision">
      <origin xyz="0 0 0" rpy="1.5707963267948966 0 0"/>
      <geometry>
        <cylinder radius="0.0508" length="0.0254"/>
      </geometry>
    </collision>
  </link>

  <joint name="omni_right" type="continuous">
    <parent link="platform"/>
    <child link="wheel_rr"/>
    <origin xyz="-0.14605 -0.12065 0" rpy="0 0 0"/>
    <axis xyz="0 1 0"/>
    <dynamics damping="0.01" friction="0.001"/>
  </joint>

</robot>

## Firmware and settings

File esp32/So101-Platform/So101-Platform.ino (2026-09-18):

// BLE robot control (So101-Platform protocol), STS bus, QMI8658 IMU, ST7789 LCD

#include <Arduino.h>
#include <Arduino_GFX_Library.h>
#include <BLEDevice.h>
#include <BLEServer.h>
#include <BLE2902.h>
#include <math.h>
#include <string.h>
#include <vector>

#include "STSDriver.h"
#include "HostSerial.h"
#include "WS_QMI8658.h"
#include "Madgwick.h"
#include "IMUCircleQueue.h"
#include "QuaternionUtil.h"

// Waveshare ESP32-S3-LCD-1.3 display + IMU
Arduino_DataBus *bus = new Arduino_ESP32SPI(38 /* DC */, 39 /* CS */, 40 /* SCK */, 41 /* MOSI */,
                                              GFX_NOT_DEFINED /* MISO */, FSPI);
Arduino_GFX *gfx = new Arduino_ST7789(bus, 42 /* RST */, 1 /* rotation: 90° CW */, true /* IPS */, 240,
                                        240, 0, 0, 0, 0);

// Pi USB (Type-C → CH343P USB-UART bridge → ESP32 UART0). Not USB CDC Serial.
#define RASPI_RX 44  // U0RXD ← CH343 TX
#define RASPI_TX 43  // U0TXD → CH343 RX
#define RASPI_BAUD 115200

// STS serial bus on the 16-pin header (see Waveshare schematic GPIO_OUT / H2+H1).
// ESP32 TX → STS RX, ESP32 RX ← STS TX
#define ARM_TX 1
#define ARM_RX 2
#define ARM_BAUD 1000000

// BLE GATT
static const char *kBleAdj[] = {"Soft", "Tiny", "Wee", "Warm", "Chub", "Calm", "Big"};
static const char *kBleNoun[] = {"Capybara", "Pika", "Panda", "Seal", "Koala", "Hedgehog"};
static char bleName[32];
static const char *kService = "4fafc201-1fb5-459e-8fcc-c5c9c331d914";
static const char *kChar = "beb5483e-36e1-4688-b7f2-e6a6a6d74324";

static void chooseBleName() {
  const size_t nAdj = sizeof(kBleAdj) / sizeof(kBleAdj[0]);
  const size_t nNoun = sizeof(kBleNoun) / sizeof(kBleNoun[0]);
  const char *adj = kBleAdj[esp_random() % nAdj];
  const char *noun = kBleNoun[esp_random() % nNoun];
  snprintf(bleName, sizeof(bleName), "%s%s", adj, noun);
}

BLECharacteristic *bleCh;
static bool bleClientConnected = false;

unsigned long prevBleTxMs = 0;
unsigned long prevBleRxMs = 0;
unsigned long prevSTSWriteMs = 0;
unsigned long prevSTSReadMs = 0;
const long STS_TX_INTERVAL = 10;
const long STS_RX_INTERVAL = STS_TX_INTERVAL;
const long BLE_RX_TIMEOUT = 250;
const long BLE_TX_INTERVAL = 40;

#pragma pack(push, 1)
struct RobotCommand {
  uint8_t cmd;
  int8_t left1; // J7
  int8_t right1; // J8
  int8_t left2; // J9 just in case for omniwheel
  int8_t right2; // J10 just in case for omniwheel
  uint8_t arm[9]; // 6 motors packed
  uint8_t leg[12]; // 8 motors packed
  uint8_t arm_enabled; // bit0=J1, bit1=J2, ...
  uint8_t leg_enabled; // bit0=J11, bit1=J12, ...
};

struct AprilTagInfo {
  uint16_t tag_id;
  int16_t tag_corners[8];
};

struct RobotState {
  uint8_t wheelEnc[6];
  uint8_t armPos[9];
  uint8_t legPos[12];
  int16_t quat[4];
  uint8_t ntags;
  AprilTagInfo tags[10];
};
#pragma pack(pop)

static_assert(sizeof(RobotCommand) == 28, "RobotCommand layout must match BLE host");
static_assert(sizeof(RobotState) == 216, "RobotState layout must match BLE host");
static constexpr uint8_t kArmEnableMask = 0x3F; // bit0=J1 .. bit5=J6
static constexpr uint8_t kLegEnableMask = 0xFF; // bit0=J11 .. bit7=J18

static constexpr uint8_t CMD_ACTUATORS = '0';
static constexpr uint8_t CMD_TAG16H5 = '1';
static constexpr uint8_t CMD_TAG25H9 = '2';
static constexpr uint8_t CMD_TAG36H11 = '3';
static constexpr size_t RASPI_CMD_PAYLOAD_LEN = 7;

RobotCommand targets;
RobotState st;

HardwareSerial RaspiSerial(0);
HostSerial hostSerial(RaspiSerial, 1);
static uint8_t raspi_alive = 0;
static uint8_t disp_raspi_alive = 0xFF;
static uint32_t disp_sts_online_mask = 0xFFFFFFFFu;

static constexpr int16_t kDispStatusPiY = 100;
static constexpr int16_t kDispStatusStsY = 124;
static constexpr int16_t kDispStatusLineH = 20;

STSDriver sts(2, ARM_RX, ARM_TX, ARM_BAUD);
static bool stsHaltSent = false;
static bool wheelVelocityPrimed = false;
static uint8_t s_armTorqueMask = 0; // which arm joints currently have torque enabled
static uint8_t s_legTorqueMask = 0; // which leg joints currently have torque enabled

/** Sketch-level STS topology (may change at runtime). */
static constexpr uint8_t kMaxServos = 18;
static constexpr uint8_t kArmJointCount = 6;
static constexpr uint8_t kLegJointCount = 8;
static constexpr uint8_t kWheelCount = 4;
static std::vector<uint8_t> gAllServoIds = {
  1, 2, 3, 4, 5, 6, 7, 8, 9, 10, 11, 12, 13, 14, 15, 16, 17, 18
};
static std::vector<uint8_t> gArmIds = {1, 2, 3, 4, 5, 6};
static std::vector<uint8_t> gWheelIds = {7, 8, 9, 10};
static std::vector<uint8_t> gLegIds = {11, 12, 13, 14, 15, 16, 17, 18};
/** IDs that currently answer SYNC_READ (subset of gAllServoIds). */
static std::vector<uint8_t> gOnlineIds;
/** bit0 = ID1 … bit17 = ID18 */
static uint32_t gOnlineMask = 0;

static uint16_t gArmRawPos[kArmJointCount];
static uint16_t gLegRawPos[kLegJointCount];
static uint16_t gWheelRawPos[kWheelCount] = {0, 0, 0, 0};

static constexpr float MADGWICK_BETA = 0.06f;
Madgwick imuFilter(MADGWICK_BETA);
static uint32_t imuMicrosPrev = 0;

static IMUCircleQueue imuCal;
static float gQuat0[4] = {1.f, 0.f, 0.f, 0.f};

struct CbServer : BLEServerCallbacks {
  void onConnect(BLEServer *) {
    bleClientConnected = true;
    prevBleRxMs = 0;
  }

  void onDisconnect(BLEServer *pServer) {
    bleClientConnected = false;
    prevBleRxMs = 0;
    stsHaltSent = false;
    BLEDevice::startAdvertising();
    if (pServer != nullptr && pServer->getAdvertising() != nullptr) {
      pServer->getAdvertising()->start();
    }
  }
};

struct CbChar : BLECharacteristicCallbacks {
  void onWrite(BLECharacteristic *c) {
    const size_t n = c->getLength();
    if (n == 0) {
      return;
    }
    const uint8_t *buf = c->getData();

    switch (buf[0]) {
      case CMD_ACTUATORS:
        if (n >= sizeof(RobotCommand)) {
          memcpy(&targets, buf, sizeof(RobotCommand));
        } else if (n >= 3) {
          targets.cmd = CMD_ACTUATORS;
          targets.left1 = (int8_t)buf[1];
          targets.right1 = (int8_t)buf[2];
          targets.left2 = 0;
          targets.right2 = 0;
        } else {
          break;
        }
        // Host teleop is symmetric; left wheel STS mounts are reversed vs right.
        targets.left1 = (int8_t)constrain(-(int)targets.left1, -125, 125);
        targets.right1 = (int8_t)constrain((int)targets.right1, -125, 125);
        targets.left2 = (int8_t)constrain(-(int)targets.left2, -125, 125);
        targets.right2 = (int8_t)constrain((int)targets.right2, -125, 125);
        prevBleRxMs = millis();
        break;

      case CMD_TAG16H5:
      case CMD_TAG25H9:
      case CMD_TAG36H11:
        if (n >= RASPI_CMD_PAYLOAD_LEN) {
          hostSerial.writeBytes((void *)buf, RASPI_CMD_PAYLOAD_LEN);
        }
        break;

      default:
        break;
    }
  }
};

static CbServer cbServer;
static CbChar cbChar;

static void rebuildOnlineIdsFromMask() {
  gOnlineIds.clear();
  for (uint8_t id : gAllServoIds) {
    if (id >= 1 && id <= kMaxServos && (gOnlineMask & (1u << (id - 1)))) {
      gOnlineIds.push_back(id);
    }
  }
}

static bool isServoOnline(uint8_t id) {
  return id >= 1 && id <= kMaxServos && (gOnlineMask & (1u << (id - 1))) != 0;
}

static void setServoOnline(uint8_t id, bool online) {
  if (id < 1 || id > kMaxServos) {
    return;
  }
  const uint32_t bit = 1u << (id - 1);
  if (online) {
    gOnlineMask |= bit;
  } else {
    gOnlineMask &= ~bit;
  }
}

static std::vector<uint8_t> filterOnline(const std::vector<uint8_t> &ids) {
  std::vector<uint8_t> out;
  out.reserve(ids.size());
  for (uint8_t id : ids) {
    if (isServoOnline(id)) {
      out.push_back(id);
    }
  }
  return out;
}

static void applyReadPositions(const std::vector<uint8_t> &ids, const std::vector<int16_t> &pos) {
  const size_t n = ids.size() < pos.size() ? ids.size() : pos.size();
  for (size_t i = 0; i < n; i++) {
    const uint8_t id = ids[i];
    const uint16_t raw = (uint16_t)(pos[i] & 0x0FFF);
    if (id >= 1 && id <= kArmJointCount) {
      gArmRawPos[id - 1] = raw;
    } else if (id >= 7 && id <= 10) {
      gWheelRawPos[id - 7] = raw;
    } else if (id >= 11 && id <= 18) {
      gLegRawPos[id - 11] = raw;
    }
  }
}

static void packU12(const uint16_t *in, int count, uint8_t *packed, int packedLen) {
  memset(packed, 0, packedLen);
  int byteidx = 0;
  bool insert2 = true;
  for (int i = 0; i < count; i++) {
    const uint16_t v = in[i] & 0x0FFF;
    if (insert2) {
      packed[byteidx++] = (uint8_t)(v & 0xFF);
      packed[byteidx] = (uint8_t)((v >> 8) & 0x0F);
    } else {
      packed[byteidx] = (uint8_t)(((v & 0x0F) << 4) | packed[byteidx]);
      byteidx++;
      packed[byteidx++] = (uint8_t)((v >> 4) & 0xFF);
    }
    insert2 = !insert2;
  }
}

static void packArm12(const uint16_t *in, uint8_t packed[9]) {
  packU12(in, kArmJointCount, packed, 9);
}

static void packLeg12(const uint16_t *in, uint8_t packed[12]) {
  packU12(in, kLegJointCount, packed, 12);
}

static void packWheelEnc12(const uint16_t in[4], uint8_t out[6]) {
  packU12(in, 4, out, 6);
}

/** Refresh online mask + packed encoders from a bus-wide SYNC_READ scan. */
static void refreshServoPresenceAndEncoders() {
  std::vector<uint8_t> foundIds;
  std::vector<int16_t> foundPos;
  gOnlineMask = 0;
  gOnlineIds.clear();
  if (!sts.scanAllServosOnline(gAllServoIds, foundIds, foundPos)) {
    return;
  }
  for (uint8_t id : foundIds) {
    setServoOnline(id, true);
  }
  rebuildOnlineIdsFromMask();
  applyReadPositions(foundIds, foundPos);
  packArm12(gArmRawPos, st.armPos);
  packLeg12(gLegRawPos, st.legPos);
  packWheelEnc12(gWheelRawPos, st.wheelEnc);
}

static void unpackU12(const uint8_t *packed, int count, uint16_t *out) {
  int byteidx = 0;
  bool extract2 = true;
  uint16_t a, b = 0;
  for (int i = 0; i < count; i++) {
    a = packed[byteidx++];
    if (extract2) {
      b = packed[byteidx++];
      out[i] = ((b & 0x0F) << 8) | a;
      b >>= 4;
    } else {
      out[i] = (a << 4) | b;
    }
    extract2 = !extract2;
  }
}

static void unpackArm12(const uint8_t packed[9], uint16_t *out) {
  unpackU12(packed, kArmJointCount, out);
}

static void unpackLeg12(const uint8_t packed[12], uint16_t *out) {
  unpackU12(packed, kLegJointCount, out);
}

static void driveArmJointsFromTargets() {
  unpackArm12(targets.arm, gArmRawPos);

  const uint8_t wantMask = targets.arm_enabled & kArmEnableMask;
  const uint8_t engageMask = (uint8_t)(wantMask & ~s_armTorqueMask);

  std::vector<uint8_t> releaseIds;
  std::vector<uint8_t> engageIds;
  std::vector<uint8_t> driveIds;
  std::vector<int16_t> drivePos;
  releaseIds.reserve(kArmJointCount);
  engageIds.reserve(kArmJointCount);
  driveIds.reserve(kArmJointCount);
  drivePos.reserve(kArmJointCount);

  for (uint8_t i = 0; i < kArmJointCount; i++) {
    const uint8_t bit = (uint8_t)(1u << i);
    const uint8_t id = (uint8_t)(i + 1);
    if (!isServoOnline(id)) {
      continue;
    }
    if (engageMask & bit) {
      engageIds.push_back(id);
    }
    if (wantMask & bit) {
      driveIds.push_back(id);
      drivePos.push_back((int16_t)gArmRawPos[i]);
    } else {
      releaseIds.push_back(id);
    }
  }

  if (!releaseIds.empty()) {
    sts.releaseTorque(releaseIds);
  }
  if (!engageIds.empty()) {
    sts.engageTorque(engageIds);
  }
  if (!driveIds.empty()) {
    sts.setAngles(driveIds, drivePos);
  }

  s_armTorqueMask = wantMask;
}

static void driveLegJointsFromTargets() {
  unpackLeg12(targets.leg, gLegRawPos);

  const uint8_t wantMask = targets.leg_enabled & kLegEnableMask;
  const uint8_t engageMask = (uint8_t)(wantMask & ~s_legTorqueMask);

  std::vector<uint8_t> releaseIds;
  std::vector<uint8_t> engageIds;
  std::vector<uint8_t> driveIds;
  std::vector<int16_t> drivePos;
  releaseIds.reserve(kLegJointCount);
  engageIds.reserve(kLegJointCount);
  driveIds.reserve(kLegJointCount);
  drivePos.reserve(kLegJointCount);

  for (uint8_t i = 0; i < kLegJointCount; i++) {
    const uint8_t bit = (uint8_t)(1u << i);
    const uint8_t id = (uint8_t)(i + 11);
    if (!isServoOnline(id)) {
      continue;
    }
    if (engageMask & bit) {
      engageIds.push_back(id);
    }
    if (wantMask & bit) {
      driveIds.push_back(id);
      drivePos.push_back((int16_t)gLegRawPos[i]);
    } else {
      releaseIds.push_back(id);
    }
  }

  if (!releaseIds.empty()) {
    sts.releaseTorque(releaseIds);
  }
  if (!engageIds.empty()) {
    sts.engageTorque(engageIds);
  }
  if (!driveIds.empty()) {
    sts.setAngles(driveIds, drivePos);
  }

  s_legTorqueMask = wantMask;
}

static int16_t wheelSpeedToSts(int8_t speed) {
  // static constexpr int16_t kStsMaxWheelSpeed = 3400;
  // static constexpr int8_t kWheelCmdScale = 27; // ±125 BLE cmd → ±3375 STS (~±3400 max)
  int16_t s = constrain((int16_t)speed * 27, -3400, 3400);
  if (s >= 0) return s;
  return (int16_t)((uint16_t)((uint16_t)(-s) | 0x8000u));
}

static void driveWheelVelocityFromTargets() {
  const std::vector<uint8_t> onlineWheels = filterOnline(gWheelIds);
  if (onlineWheels.empty()) {
    return;
  }
  const bool anyCmd =
    targets.left1 != 0 || targets.right1 != 0 || targets.left2 != 0 || targets.right2 != 0;
  if (!wheelVelocityPrimed && anyCmd) {
    // setup() may run before servo power is up; re-enter velocity mode on first drive.
    sts.enableVelocityMode(onlineWheels);
    wheelVelocityPrimed = true;
  }
  std::vector<int16_t> wheelSpeed;
  wheelSpeed.reserve(onlineWheels.size());
  for (uint8_t id : onlineWheels) {
    if (id == 7) {
      wheelSpeed.push_back(wheelSpeedToSts(targets.left1));
    } else if (id == 8) {
      wheelSpeed.push_back(wheelSpeedToSts(targets.right1));
    } else if (id == 9) {
      wheelSpeed.push_back(wheelSpeedToSts(targets.left2));
    } else if (id == 10) {
      wheelSpeed.push_back(wheelSpeedToSts(targets.right2));
    }
  }
  if (wheelSpeed.size() == onlineWheels.size()) {
    sts.setSpeed(onlineWheels, wheelSpeed);
  }
}

static bool isBleActive(unsigned long now) {
  if (prevBleRxMs == 0) {
    return false;
  }
  return now - prevBleRxMs < BLE_RX_TIMEOUT;
}

static bool sampleIMU(float q[4]) {
  float ax, ay, az, gx, gy, gz, tempC;
  if (!QMI8658_read(ax, ay, az, gx, gy, gz, tempC)) {
    return false;
  }

  const uint32_t nowUs = micros();
  float dt = (nowUs - imuMicrosPrev) * 1e-6f;
  imuMicrosPrev = nowUs;
  if (dt <= 0.f || dt > 0.2f) {
    return false;
  }

  imuFilter.updateIMU(gx * DEG_TO_RAD, gy * DEG_TO_RAD, gz * DEG_TO_RAD, ax, ay, az, dt);
  q[0] = imuFilter.q0();
  q[1] = imuFilter.q1();
  q[2] = imuFilter.q2();
  q[3] = imuFilter.q3();
  return true;
}

static void calibrateIMUZero() {
  imuCal.reset();
  while (!imuCal.isFull()) {
    float q[4];
    if (sampleIMU(q)) {
      imuCal.push(q[0], q[1], q[2], q[3]);
    }
    delay(5);
  }
  if (!imuCal.averageQuat(gQuat0)) {
    gQuat0[0] = 1.f;
    gQuat0[1] = gQuat0[2] = gQuat0[3] = 0.f;
  }
}

static void drawStatusLine(int16_t y, const char *label, bool ok) {
  gfx->fillRect(8, y, 224, kDispStatusLineH, RGB565_BLACK);
  gfx->setTextSize(2);
  gfx->setCursor(8, y);
  if (ok) {
    gfx->setTextColor(RGB565(0, 255, 0), RGB565_BLACK);
    gfx->print(label);
    gfx->println(" online");
  } else {
    gfx->setTextColor(RGB565_DARKGREY, RGB565_BLACK);
    gfx->print(label);
    gfx->println(" offline");
  }
}

static void drawStsStatusLine(int16_t y, uint32_t onlineMask) {
  gfx->fillRect(8, y, 224, kDispStatusLineH * 2, RGB565_BLACK);
  gfx->setTextSize(2);
  gfx->setCursor(8, y);
  const bool any = onlineMask != 0;
  if (any) {
    gfx->setTextColor(RGB565(0, 255, 0), RGB565_BLACK);
    gfx->println("STS found");
  } else {
    gfx->setTextColor(RGB565_DARKGREY, RGB565_BLACK);
    gfx->println("STS missing");
  }

  gfx->setTextSize(1);
  gfx->setCursor(8, y + kDispStatusLineH);
  if (!any) {
    gfx->setTextColor(RGB565_DARKGREY, RGB565_BLACK);
    gfx->print("-");
    return;
  }
  gfx->setTextColor(RGB565(0, 255, 0), RGB565_BLACK);
  bool first = true;
  for (uint8_t id = 1; id <= kMaxServos; id++) {
    if (onlineMask & (1u << (id - 1))) {
      if (!first) {
        gfx->print(' ');
      }
      gfx->print(id);
      first = false;
    }
  }
}

static void updateStatusDisplayIfChanged() {
  if (raspi_alive != disp_raspi_alive) {
    disp_raspi_alive = raspi_alive;
    drawStatusLine(kDispStatusPiY, "Pi", raspi_alive != 0);
  }
  if (gOnlineMask != disp_sts_online_mask) {
    disp_sts_online_mask = gOnlineMask;
    drawStsStatusLine(kDispStatusStsY, gOnlineMask);
  }
}

static void initDisplay() {
  gfx->fillScreen(RGB565_BLACK);

  gfx->setTextColor(RGB565_CYAN, RGB565_BLACK);
  gfx->setTextSize(2);
  gfx->setCursor(8, 8);
  gfx->println("BLE Name");

  gfx->setTextColor(RGB565_WHITE, RGB565_BLACK);
  gfx->setTextSize(3);
  gfx->setCursor(8, 32);
  gfx->println(bleName);
}

void setup() {
  chooseBleName();

  gfx->begin(40000000);
  initDisplay();
  updateStatusDisplayIfChanged();

  hostSerial.begin(RASPI_BAUD, RASPI_RX, RASPI_TX);

  memset(&targets, 0, sizeof(targets));
  memset(&st, 0, sizeof(st));

  QMI8658_Init();
  imuMicrosPrev = micros();
  calibrateIMUZero();
  st.quat[0] = 1000;
  st.quat[1] = st.quat[2] = st.quat[3] = 0;

  BLEDevice::init(bleName);
  BLEDevice::setMTU(247);

  BLEServer *srv = BLEDevice::createServer();
  srv->setCallbacks(&cbServer);

  BLEService *svc = srv->createService(kService);
  bleCh = svc->createCharacteristic(kChar,
    BLECharacteristic::PROPERTY_READ |
    BLECharacteristic::PROPERTY_WRITE |
    BLECharacteristic::PROPERTY_WRITE_NR |
    BLECharacteristic::PROPERTY_NOTIFY);
  bleCh->addDescriptor(new BLE2902());
  bleCh->setCallbacks(&cbChar);
  bleCh->setValue("ok");

  svc->start();

  BLEAdvertising *a = BLEDevice::getAdvertising();
  a->addServiceUUID(kService);
  a->setScanResponse(true);
  a->setMinPreferred(0x06);
  a->setMaxPreferred(0x12);
  BLEDevice::startAdvertising();

  sts.begin();
  refreshServoPresenceAndEncoders();
  updateStatusDisplayIfChanged();
  {
    const std::vector<uint8_t> onlineWheels = filterOnline(gWheelIds);
    if (!onlineWheels.empty()) {
      sts.enableVelocityMode(onlineWheels);
      wheelVelocityPrimed = true;
    }
  }
}

void loop() {
  float qNow[4] = {imuFilter.q0(), imuFilter.q1(), imuFilter.q2(), imuFilter.q3()};
  if (sampleIMU(qNow)) {
    imuCal.push(qNow[0], qNow[1], qNow[2], qNow[3]);
  }

  const unsigned long currentMs = millis();
  if (bleClientConnected && currentMs - prevBleTxMs >= BLE_TX_INTERVAL) {
    prevBleTxMs = currentMs;
    float qBle[4];
    if (!imuCal.weightedAverageQuat(qBle)) {
      qBle[0] = qNow[0];
      qBle[1] = qNow[1];
      qBle[2] = qNow[2];
      qBle[3] = qNow[3];
    }
    float qRel[4];
    quat_diff(gQuat0, qBle, qRel);
    st.quat[0] = quat_unit_to_milli(qRel[0]);
    st.quat[1] = quat_unit_to_milli(qRel[1]);
    st.quat[2] = quat_unit_to_milli(qRel[2]);
    st.quat[3] = quat_unit_to_milli(qRel[3]);
    bleCh->setValue((uint8_t *)&st, sizeof(st));
    bleCh->notify();
  }

  message_t *msg = hostSerial.readMessage();
  if (msg == STIMEOUT) {
    st.ntags = 0;
    memset(st.tags, 0, 10 * sizeof(AprilTagInfo));
    raspi_alive = 0;
  } else if (msg != nullptr && msg->length >= 1) {
    raspi_alive = 1;
    st.ntags = msg->data[0] & 0x1F; // low 5 bits are the ntags count
    if (st.ntags > 10) {
      st.ntags = 10;
    }
    const size_t need = 1 + (size_t)st.ntags * sizeof(AprilTagInfo);
    if (msg->length >= (int)need && st.ntags > 0) {
      memcpy(st.tags, &msg->data[1], st.ntags * sizeof(AprilTagInfo));
    } else if (st.ntags > 0) {
      st.ntags = 0;
    }
    if (st.ntags < 10) {
      memset(&st.tags[st.ntags], 0, (10 - st.ntags) * sizeof(AprilTagInfo));
    }
    st.ntags = st.ntags | (raspi_alive << 7); // bit7 = raspi alive for BLE hosts
  }
  updateStatusDisplayIfChanged();

  if (isBleActive(currentMs)) {
    stsHaltSent = false;
    if (currentMs - prevSTSWriteMs >= STS_TX_INTERVAL) {
      prevSTSWriteMs = currentMs;
      driveArmJointsFromTargets();
      driveLegJointsFromTargets();
      driveWheelVelocityFromTargets();
    }
  } else if (prevBleRxMs != 0 && !stsHaltSent) {
    const std::vector<uint8_t> online = filterOnline(gAllServoIds);
    if (!online.empty()) {
      sts.halt(online);
    }
    if (s_armTorqueMask != 0) {
      const std::vector<uint8_t> onlineArms = filterOnline(gArmIds);
      if (!onlineArms.empty()) {
        sts.releaseTorque(onlineArms);
      }
      s_armTorqueMask = 0;
    }
    if (s_legTorqueMask != 0) {
      const std::vector<uint8_t> onlineLegs = filterOnline(gLegIds);
      if (!onlineLegs.empty()) {
        sts.releaseTorque(onlineLegs);
      }
      s_legTorqueMask = 0;
    }
    stsHaltSent = true;
  }

  if (currentMs - prevSTSReadMs >= STS_RX_INTERVAL) {
    prevSTSReadMs = currentMs;
    refreshServoPresenceAndEncoders();
    updateStatusDisplayIfChanged();
  }
}

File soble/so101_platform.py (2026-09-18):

"""BLE interface to so101base.ino (RobotState notify + RobotCommand write).
"""

from __future__ import annotations

import asyncio
import multiprocessing as mp
import platform
import struct
import time

import cv2
import numpy as np
from bleak import BleakClient, BleakScanner
from bleak.backends.device import BLEDevice

from soble.sts_protocol import (
    ARM_JOINT_COUNT,
    LEG_JOINT_COUNT,
    parse_arm_joints,
    parse_leg_joints,
)

# BLE worker must use spawn on Linux — fork inherits parent threads/state and breaks asyncio/BlueZ.
MP_CTX = mp.get_context("spawn")

SERVICE_UUID = "4fafc201-1fb5-459e-8fcc-c5c9c331d914"
CHAR_UUID = "beb5483e-36e1-4688-b7f2-e6a6a6d74324"

CMD_ACTUATOR_LEN = 28  # cmd + 4 wheels + arm[9] + leg[12] + enables — matches RobotCommand
CMD_RASPI_LEN = 12  # cmd + raspi union (forwarded as 7 bytes on ESP32)
CMD_ACTUATORS = ord("0")
CMD_TAG16H5 = ord("1")
CMD_TAG25H9 = ord("2")
CMD_TAG36H11 = ord("3")
ARM_ENABLE_MASK = 0x3F  # bit0=J1 .. bit5=J6 — all arm joints engaged
LEG_ENABLE_MASK = 0xFF  # bit0=J11 .. bit7=J18 — all leg joints engaged
ARM_PACKED_LEN = 9
LEG_PACKED_LEN = 12
ARM_CENTER_RAW = 2048  # mid of 0..4095 — default when leader not connected
STATE_LEN = 216  # wheelEnc[6] + arm[9] + leg[12] + quat[8] + ntags + tags[180]


async def _prepare_ble_link(
    client: BleakClient,
    char_uuid: str = CHAR_UUID,
    *,
    need_notify_len: int = STATE_LEN,
) -> None:
    """Negotiate ATT MTU for robot notifies; warn only if payload looks too small."""
    _ = client.services
    # BleakClient.exchange_mtu() is not implemented on the BlueZ backend (Linux).
    # Use backend._acquire_mtu() instead — AcquireWrite or AcquireNotify via BlueZ,
    # which sets _mtu_size so client.mtu_size is not the default 23.
    backend = client._backend
    acquire_mtu = getattr(backend, "_acquire_mtu", None)
    if acquire_mtu is not None:
        try:
            await acquire_mtu()
        except Exception as exc:
            print(
                f"MTU acquire skipped: {type(exc).__name__}: {exc!r}",
                flush=True,
            )

    char = client.services.get_characteristic(char_uuid)
    if char is None:
        raise RuntimeError(f"GATT characteristic not found: {char_uuid}")

    link_mtu = int(client.mtu_size)
    prop_payload = int(char.max_write_without_response_size)
    effective_payload = max(prop_payload, link_mtu - 3)
    if effective_payload < need_notify_len:
        print(
            f"Warning: BLE payload limit {effective_payload} < robot notify "
            f"{need_notify_len}; state may be truncated",
            flush=True,
        )
TAG_INFO_LEN = 18
MAX_TAGS = 10
TAG_BLOB_LEN = MAX_TAGS * TAG_INFO_LEN

TX_INTERVAL = 0.04  # 25 Hz — matches BLE_TX_INTERVAL on ESP32
DEFAULT_RECONNECT_DELAY_S = 0.25
STALE_NOTIFY_S = 0.3  # reconnect if no RobotState notify within this window


def _gatt_write_with_response() -> bool:
    """Use ATT write-with-response except on Linux, where it blocks BlueZ notify delivery."""
    return platform.system() == "Windows" or platform.system() == "Darwin"

# Must match raspi/detect_atags.py (origin 640,360 and * 25 packing)
TAG_ORIGIN_X = 640.0
TAG_ORIGIN_Y = 360.0
TAG_CORNER_SCALE = 25.0

AprilTagList = list[tuple[int, tuple[int, ...]]]


def _pack_u12(joints: list[int], packed_len: int) -> bytes:
    packed = bytearray(packed_len)
    byteidx = 0
    insert2 = True
    for v in joints:
        v &= 0x0FFF
        if insert2:
            packed[byteidx] = v & 0xFF
            byteidx += 1
            packed[byteidx] = (v >> 8) & 0x0F
        else:
            packed[byteidx] = ((v & 0x0F) << 4) | packed[byteidx]
            byteidx += 1
            packed[byteidx] = (v >> 4) & 0xFF
            byteidx += 1
        insert2 = not insert2
    return bytes(packed)


def _unpack_u12(packed: bytes, count: int) -> list[int]:
    out: list[int] = []
    byteidx = 0
    extract2 = True
    b = 0
    for _ in range(count):
        a = packed[byteidx]
        byteidx += 1
        if extract2:
            b = packed[byteidx]
            byteidx += 1
            out.append(((b & 0x0F) << 8) | a)
            b >>= 4
        else:
            out.append((a << 4) | b)
        extract2 = not extract2
    return out


def _pack_arm12(joints: list[int]) -> bytes:
    return _pack_u12(joints, ARM_PACKED_LEN)


def _unpack_arm12(packed: bytes) -> list[int]:
    return _unpack_u12(packed, ARM_JOINT_COUNT)


def _pack_leg12(joints: list[int]) -> bytes:
    return _pack_u12(joints, LEG_PACKED_LEN)


def _unpack_leg12(packed: bytes) -> list[int]:
    return _unpack_u12(packed, LEG_JOINT_COUNT)


def _pack_wheel_enc12(values: list[int]) -> bytes:
    """Pack four 12-bit wheel encoders into 6 bytes."""
    if len(values) != 4:
        raise ValueError(f"expected 4 wheel encoders, got {len(values)}")
    return _pack_u12([int(v) & 0x0FFF for v in values], 6)


def _unpack_enc12(packed: bytes) -> tuple[int, int, int, int]:
    """Unpack four 12-bit wheel encoders from 6 bytes (left1, right1, left2, right2)."""
    vals = _unpack_u12(packed[:6], 4)
    return vals[0], vals[1], vals[2], vals[3]


def _pack_robot_command(
    left: int,
    right: int,
    arm_packed: bytes,
    *,
    left2: int = 0,
    right2: int = 0,
    leg_packed: bytes | None = None,
    arm_disabled: bool = False,
    leg_disabled: bool = False,
) -> bytes:
    """BLE teleop matching ESP32 RobotCommand (28 bytes)."""
    if len(arm_packed) != ARM_PACKED_LEN:
        arm_packed = _pack_arm12([ARM_CENTER_RAW] * ARM_JOINT_COUNT)
    if leg_packed is None or len(leg_packed) != LEG_PACKED_LEN:
        leg_packed = _pack_leg12([ARM_CENTER_RAW] * LEG_JOINT_COUNT)
    left = max(-125, min(125, int(left)))
    right = max(-125, min(125, int(right)))
    left2 = max(-125, min(125, int(left2)))
    right2 = max(-125, min(125, int(right2)))
    arm_enabled = 0 if arm_disabled else ARM_ENABLE_MASK
    leg_enabled = 0 if leg_disabled else LEG_ENABLE_MASK
    return (
        struct.pack("<Bbbbb", CMD_ACTUATORS, left, right, left2, right2)
        + arm_packed
        + leg_packed
        + bytes([arm_enabled, leg_enabled])
    )


def _pack_raspi_ble_command(cmd: int) -> bytes:
    """BLE → ESP32 → USB → Pi (detect_atags.py). cmd is tag family '1'/'2'/'3'."""
    return struct.pack("<B", cmd & 0xFF) + b"\x00" * (CMD_RASPI_LEN - 1)
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

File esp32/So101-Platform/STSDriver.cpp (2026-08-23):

#include "STSDriver.h"
#include <string.h>

static const uint8_t INST_SYNC_READ = 0x82;
static const uint8_t INST_SYNC_WRITE = 0x83;
static const uint8_t REG_TORQUE_ENABLE = 40;
static const uint8_t REG_ACCELERATION = 41;
static const uint8_t REG_MODE = 33;
static const uint8_t MODE_VELOCITY = 1;
static const uint8_t REG_PRESENT_POSITION = 0x38;
static const uint8_t REG_GOAL_POSITION = 0x2A;
static const uint8_t REG_GOAL_SPEED_L = 46;
static const uint8_t ARM_DATA_LEN = 2;
static const uint8_t RESP_FRAME_LEN = 8;

static const uint32_t kRxIdleUs = 400;
static const uint32_t kRxMaxUs = 8000;
static constexpr uint8_t kWheelAcceleration = 0;
/** Practical FeeTech SYNC_* packet limit (IDs + framing). */
static constexpr size_t kMaxIdsPerPacket = 20;

STSDriver::STSDriver(uint8_t uartNum, int rxPin, int txPin, uint32_t baud)
    : _serial(uartNum),
      _rxPin(rxPin),
      _txPin(txPin),
      _baud(baud),
      _presentValid(false),
      _halted(false),
      _wheelVelocityModeReady(false) {}

void STSDriver::begin() {
  _serial.begin(_baud, SERIAL_8N1, _rxPin, _txPin);
  while (_serial.available() > 0) {
    _serial.read();
  }
}

bool STSDriver::idsUsable(const std::vector<uint8_t> &ids) const {
  return !ids.empty() && ids.size() <= kMaxIdsPerPacket;
}

uint8_t STSDriver::checksum(const uint8_t *bodyFromId, size_t n) {
  uint16_t sum = 0;
  for (size_t i = 0; i < n; i++) {
    sum += bodyFromId[i];
  }
  return (uint8_t)((~sum) & 0xFF);
}

size_t STSDriver::buildSyncReadPacket(uint8_t *out, const uint8_t *ids, uint8_t count) {
  const uint8_t lenField = (uint8_t)(count + 4);
  size_t idx = 0;
  out[idx++] = 0xFF;
  out[idx++] = 0xFF;
  out[idx++] = 0xFE;
  out[idx++] = lenField;
  out[idx++] = INST_SYNC_READ;
  out[idx++] = REG_PRESENT_POSITION;
  out[idx++] = ARM_DATA_LEN;
  for (uint8_t i = 0; i < count; i++) {
    out[idx++] = ids[i];
  }
  out[idx++] = checksum(&out[2], idx - 2);
  return idx;
}

int STSDriver::parseStatusFrame(const uint8_t *frame) {
  if (frame[0] != 0xFF || frame[1] != 0xFF) {
    return -1;
  }
  uint16_t sum = 0;
  for (size_t i = 2; i < 7; i++) {
    sum += frame[i];
  }
  if ((uint8_t)((~sum) & 0xFF) != frame[7]) {
    return -1;
  }
  return (int)((frame[6] << 8) | frame[5]);
}

int STSDriver::findPosition(const uint8_t *buf, size_t buflen, uint8_t id) {
  // Same approach as WebUI findPositionForId: slide one byte at a time and
  // validate each candidate with parseStatusFrame.
  if (buflen < RESP_FRAME_LEN) {
    return -1;
  }
  for (size_t i = 0; i + RESP_FRAME_LEN <= buflen; i++) {
    if (buf[i] == 0xFF && buf[i + 1] == 0xFF && buf[i + 2] == id) {
      const int pos = parseStatusFrame(&buf[i]);
      if (pos >= 0) {
        return pos;
      }
    }
  }
  return -1;
}

bool STSDriver::readAngles(const std::vector<uint8_t> &ids, std::vector<int16_t> &out) {
  if (!idsUsable(ids)) {
    return false;
  }
  const uint8_t count = (uint8_t)ids.size();
  const size_t expectRx = (size_t)count * RESP_FRAME_LEN;

  std::vector<uint8_t> tx(32 + count);
  const size_t txLen = buildSyncReadPacket(tx.data(), ids.data(), count);
  _rxBuf.assign(expectRx, 0);

  while (_serial.available() > 0) {
    _serial.read();
  }
  _serial.write(tx.data(), txLen);
  _serial.flush();

  size_t n = 0;
  const uint32_t t0 = micros();
  uint32_t lastByteUs = 0;
  while ((uint32_t)(micros() - t0) < kRxMaxUs) {
    while (_serial.available() > 0 && n < expectRx) {
      _rxBuf[n++] = (uint8_t)_serial.read();
      lastByteUs = micros();
    }
    if (n >= expectRx) {
      break;
    }
    if (n > 0 && lastByteUs > 0 && (uint32_t)(micros() - lastByteUs) > kRxIdleUs) {
      break;
    }
  }

  out.assign(count, -1);
  if (n < RESP_FRAME_LEN) {
    _presentValid = false;
    return false;
  }

  size_t found = 0;
  for (uint8_t i = 0; i < count; i++) {
    const int pos = findPosition(_rxBuf.data(), n, ids[i]);
    if (pos >= 0) {
      out[i] = (int16_t)pos;
      found++;
    }
  }
  _presentValid = found > 0;
  return found > 0;
}

bool STSDriver::scanAllServosOnline(const std::vector<uint8_t> &candidateIds,
                                    std::vector<uint8_t> &foundIds,
                                    std::vector<int16_t> &foundPos) {
  foundIds.clear();
  foundPos.clear();
  std::vector<int16_t> raw;
  if (!readAngles(candidateIds, raw)) {
    return false;
  }
  foundIds.reserve(candidateIds.size());
  foundPos.reserve(candidateIds.size());
  for (size_t i = 0; i < candidateIds.size() && i < raw.size(); i++) {
    if (raw[i] < 0) {
      continue;
    }
    foundIds.push_back(candidateIds[i]);
    foundPos.push_back(raw[i]);
  }
  return !foundIds.empty();
}
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

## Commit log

2026-05-23 Use write-with-response for BLE command writes
    macOS CoreBluetooth silently drops writes with response=False when the
    characteristic does not advertise WriteWithoutResponse, so commands never
    reached the ESP32 on Mac while notifications worked fine. BlueZ on Linux
    tolerates this, which masked the issue. Switching to response=True works
    on both hosts at the 25 Hz TX_INTERVAL.
    [so101_platform.py]
2026-05-25 add sourcing parts section
    [ESP32CarrierMount.stl, EncoderAxle.stl, EncoderBody.stl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]
2026-05-25 update stl
    [ESP32CarrierMount.stl, EncoderAxle.stl, EncoderBody.stl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]
2026-05-26 fix atag pose estimation
    [so101_platform.py]
2026-05-27 add assembly steps (mechanical)
2026-06-02 add wiring docs
2026-06-02 fix wiring
2026-06-03 fix docs
    [so101-pcb-camera-wrist-mount.stl]
2026-06-12 add firmware and comms for esp32-s3-lcd-1.3
2026-06-13 Fully 3DP chassis for SO-ARM101 (KiloChassis)
    Random, non wide use name. For uploading STL files to.
2026-06-15 Added update on STL file upload & future plan
2026-06-15 update assembly
2026-06-16 rm stale components
    [so101-pcb-camera-wrist-mount.stl, so101platform-parts.stl]
2026-06-16 omni wheel instructions
2026-06-16 add docs for front wheel assembly
2026-06-17 add wiring
2026-06-17 align parts with STL
2026-06-18 add IMX708 mount
    [SO-ARM101_IMX708_wrist_mount.stl]
2026-06-18 add esp32 patches
2026-06-19 add electronics assembly
    [Front Wheels Grippy v2.stl]
2026-06-19 update wiring
2026-06-19 Move assembly guide to wiki and drop step images from tree.
    Assembly docs and illustrations now live on the GitHub wiki; keep only
    Platform.jpg in media/ and point README and systemd docs at the wiki.
2026-06-23 update so101 assets
    [ChassisV2.stl, FrontWheel.stl, Omniwheel.stl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]
2026-06-25 add sim bits, minor fixes
    [SO-ARM101_IMX708_wrist_mount.stl]
2026-07-01 rm min_config, use standard config only
    [so101_platform.urdf]
2026-07-12 update omniwheel roller
    [Omni Wheel Frame.stl, Roller.stl]
2026-07-12 add files for front wheel adapter for a vex wheel
    [Front Axle Halve.stl, Servo Coupler.stl]
2026-07-15 update frame to have less gap
    [Omni Wheel Frame.stl]
2026-07-18 fix: checksum on sts
    [sts_protocol.py]
2026-07-22 rm unneeded STL
    [Roller Axle.stl]
2026-07-22 add wheel
2026-07-24 update frame count
2026-07-24 add one-piece bolts
    [Front Drive Bolt v2.stl, Main Base Bolt v2.stl, Rear Drive Bolt.stl]
2026-07-24 add servo clamp stl
    [Servo Clamp.stl]
2026-08-17 Renamed the local Base64.h to Base64_bot.h to avoid conflicts with other libraries on case-insensitive filesystems
2026-08-21 add status to the device display
2026-08-23 async discovery of sts servos
2026-09-18 remove camera stream
